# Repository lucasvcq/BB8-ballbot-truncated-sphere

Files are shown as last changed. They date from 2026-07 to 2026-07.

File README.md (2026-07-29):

# Ballbot — Self-Balancing Truncated-Sphere Robot

A truncated-sphere robot that moves by shifting its center of gravity and using a reaction wheel, controlled remotely through a web interface on a phone. Built from scratch over a full academic year by a team of 6.

## Overview

The robot's shape is a truncated sphere. Movement isn't achieved with wheels or legs, but by:

- **Shifting its internal center of gravity** to lean and roll in a direction
- A **reaction/inertia wheel** to control orientation and stabilize the robot

The whole system is piloted remotely via a **web interface accessible from a phone**.

Team of 6, full academic year (design, build, and control from scratch).

[📄 Poster](<RENDU FINAL/Blue Modern Scientific Poster (3).pdf>)

## My Role

- Embedded control code (Arduino + ESP32)
- Motor selection and driving
- Piloting/control logic (web interface ↔ robot communication)
- **Closed-loop control (asservissement)** for balance and movement
- Full wiring and soldering

## Tech Stack

- **Hardware:** Arduino, ESP32
- **Software:** HTML (web control interface), embedded C/C++
- **Modeling/Simulation:** MATLAB (control system modeling and simulation, used to design and validate the closed-loop control before implementation)
- **Tools:** VS Code, Git
- **Skills:** Soldering, closed-loop control design

## Architecture

```text
Phone (web interface, HTML)
        │  Wi-Fi
        ▼
     ESP32 ──► Arduino ──► Motors + Reaction wheel
        ▲
        └── Sensors (feedback for closed-loop control)
```

## Key Technical Points

- Designing a **closed-loop control system (asservissement)** to keep a spherical robot balanced and move it in a controlled direction using only a center-of-gravity shift + reaction wheel — no wheels/legs
- **Modeling and simulating the control system in MATLAB** before implementing it on hardware, to validate stability and tune parameters ahead of physical testing
- Wi-Fi communication between a phone-based web interface (ESP32) and the low-level motor control (Arduino)
- Mechanical design constraints of a truncated-sphere form factor

## Demo

<table border="0" style="border-collapse: collapse; border: none;">
  <tr style="border: none;">
    <td align="center" width="50%" style="border: none;">
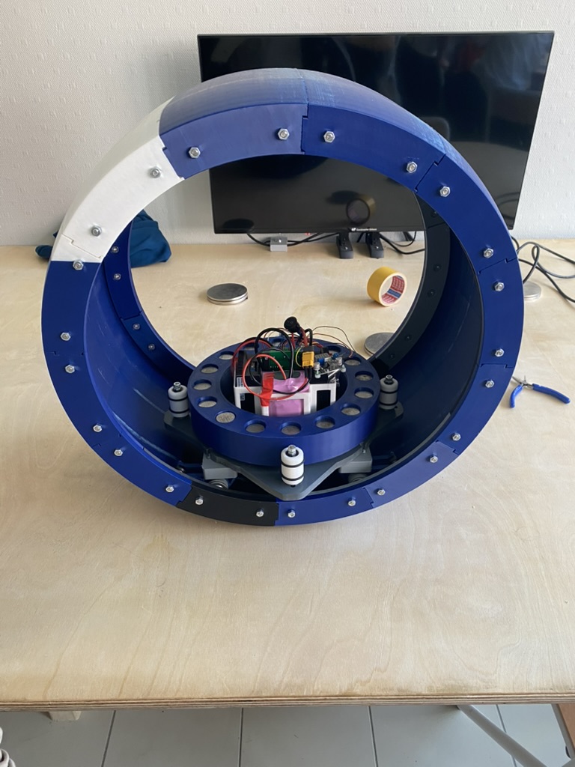
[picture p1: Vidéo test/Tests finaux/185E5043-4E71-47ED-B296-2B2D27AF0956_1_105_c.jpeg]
Picture of the robot
      
      <br>
      <sub>Picture of the robot</sub>
    </td>
    <td align="center" width="50%" style="border: none;">
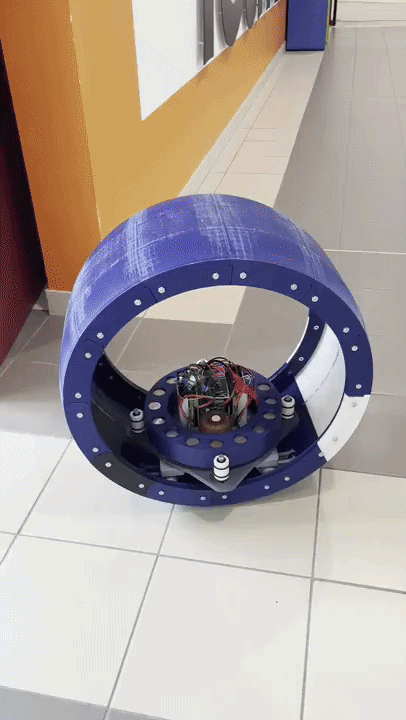
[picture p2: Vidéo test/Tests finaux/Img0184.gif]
Video of the robot moving
      
      <br>
      <sub>Video of the robot moving</sub>
    </td>
  </tr>
</table>

<!-- Add photos/video of the robot moving + the web control interface -->

## Context

School project — ICAM, 3rd year engineering, group project (6 students, full year, built from scratch).

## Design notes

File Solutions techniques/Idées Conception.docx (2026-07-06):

Idées Conception

- Le robot

On déplace notre masse sur les 3 axes dont un qui gère la direction et le reste sert pour le déplacement linéaire.

- Rail interne

contact par adhérence ou par engrenage

- 2 roues libres et 1 roue motorisée
- 1 roue libre et 2 roues motorisées
- Masse latérale

cette masse permet de faire pencher le robot pour le faire tourner, la commande dirigera l’angle que doit suivre le robot pour tourner correctement via les capteurs

- poulie courroie (contrôle X)
- pignon crémaillère
- vis sans fin
- (max speed)
- même système que la roue du rail interne mis en perpendiculaire (voir photo)
- Capteurs:
- Inclinomètre
- Gyroscope

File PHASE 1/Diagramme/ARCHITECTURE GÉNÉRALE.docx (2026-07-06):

Rail partiel

Masse latérale

Roue de contact motorisé

Capteur

Roues de contact libre

Batterie

Roue de contact motorisé

Carte de commande

Chassi

Rail

Masse principale

Roues de contact libre

Composants électroniques

Support masse latérale

Roue principale

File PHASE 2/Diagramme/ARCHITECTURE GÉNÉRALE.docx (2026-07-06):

Roue de contact motorisé

Roue de contact motorisé

Roues de contact libre

Composants électroniques

Roue d’inertie

Capteur

Roues de contact libre

Batterie

Carte de commande

Chassi

Roue principale

Rail

Masse principale

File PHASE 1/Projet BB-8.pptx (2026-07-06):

## Projet BB-8

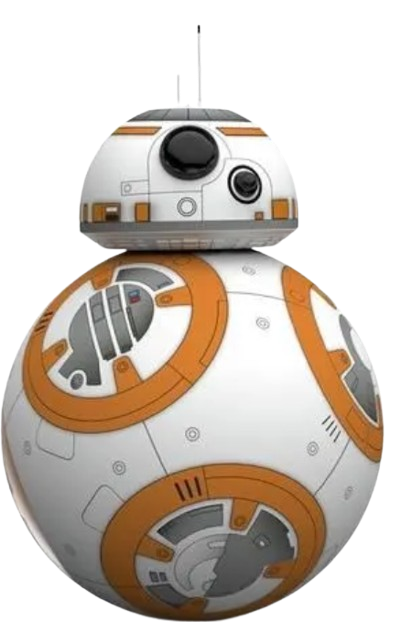
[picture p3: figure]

Groupe : I_Roue_6

## Sommaire

- Organigramme de l'équipe
- Veille sur l'existant
- Diagramme pieuvre et FAST
- Audit sur l’existant
- Planning
- Conclusion

## Organigramme de l’équipe

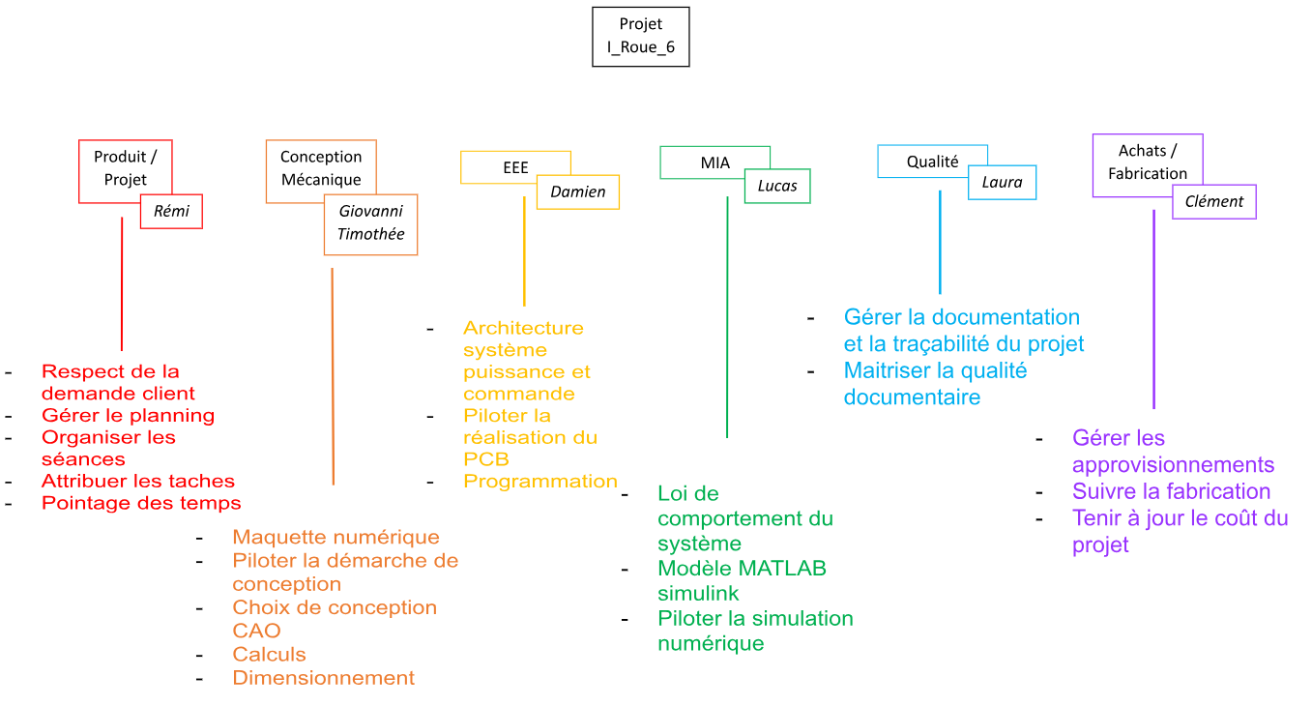
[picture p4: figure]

## Veille sur l’existant

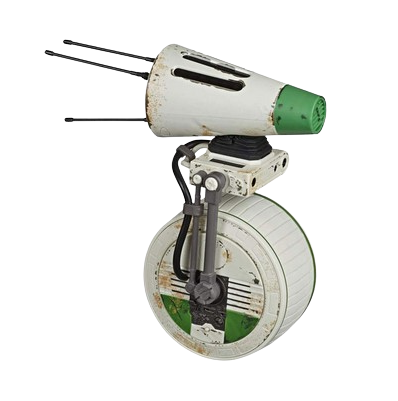
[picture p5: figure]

Robot Gyroroue
- Système mono roue avec capacité de tourner par inclinaison du centre de masse
- Centre de masse à l'extérieur

Robot D-0 inspiration star wars
- Deux roues disjointes
- Système intéressant mais pas
compatible avec le cahier des charges

Ringbot
- Centre de masse dans la roue
- Roue creuse
- Roule grâce au déplacement du centre de masse sur les rails intérieurs
- Equilibrage grâce au déplacement du centre de masse le long de l’axe de la roue
- Système le plus intéressant pour nous

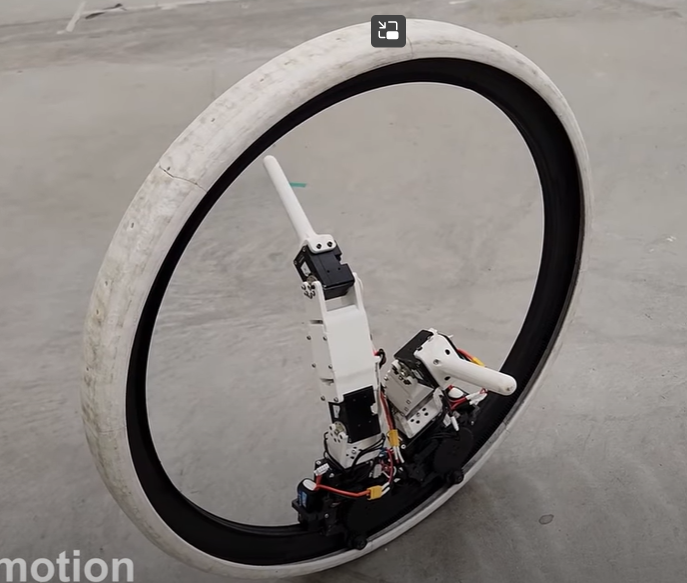
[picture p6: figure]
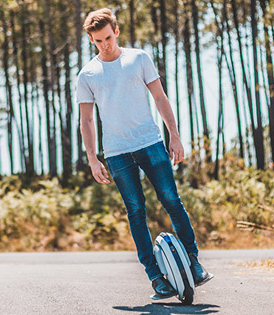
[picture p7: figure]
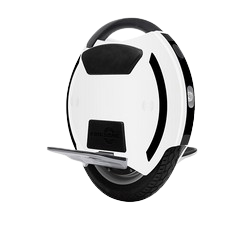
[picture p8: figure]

## Diagramme pieuvre et FAST

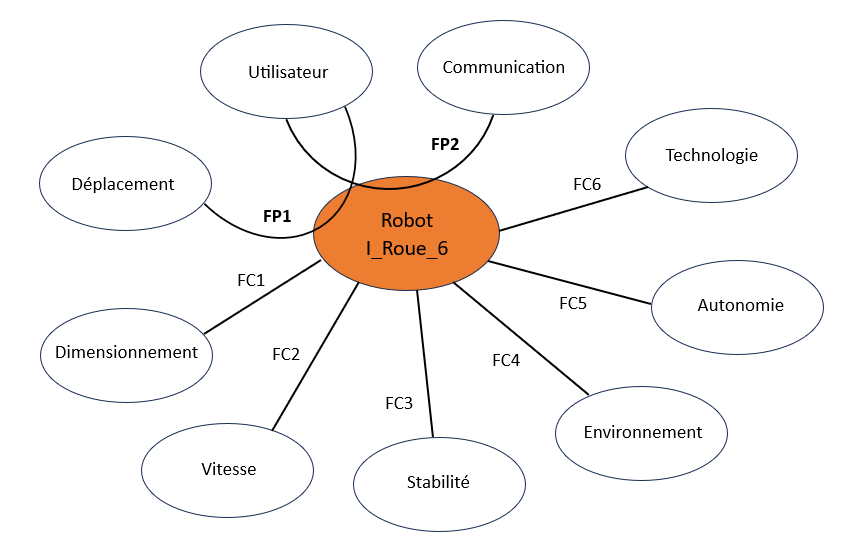
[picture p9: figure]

Diagramme FAST

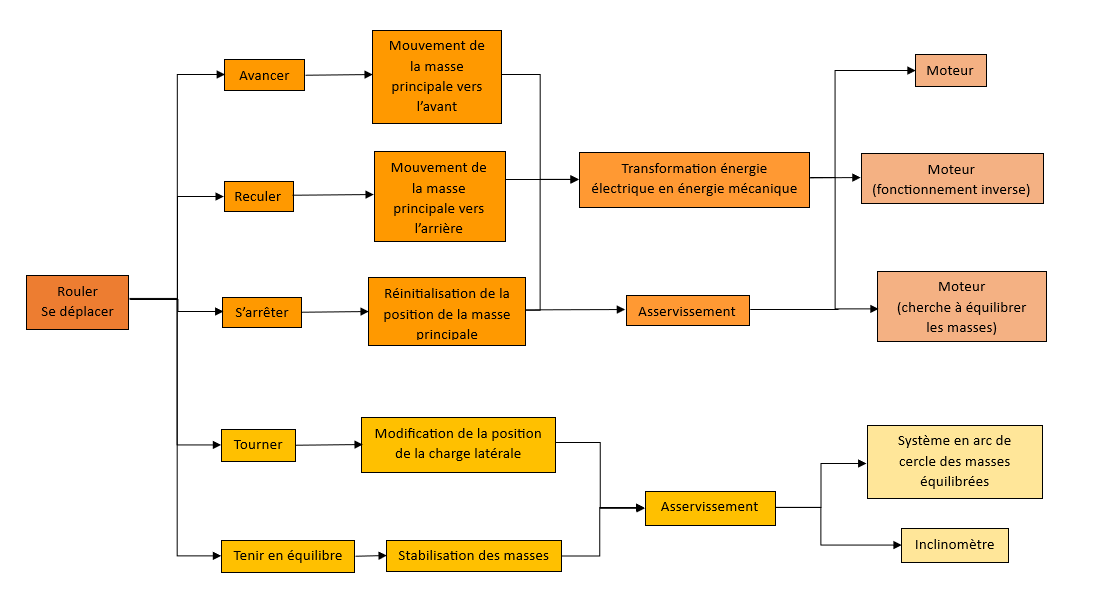
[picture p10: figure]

Diagramme pieuvre

## Audit sur l’existant

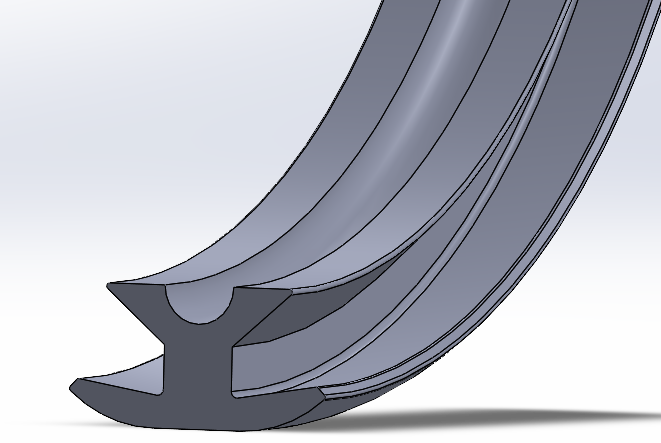
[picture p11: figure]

Rail interne
- Quatre roues libres et
une roue motorisée
=> On déplace la masse principale
=> Déplacement linéaire de la
masse pour le faire

Masse latérale
- Permet de faire
pencher le robot
pour le faire tourner

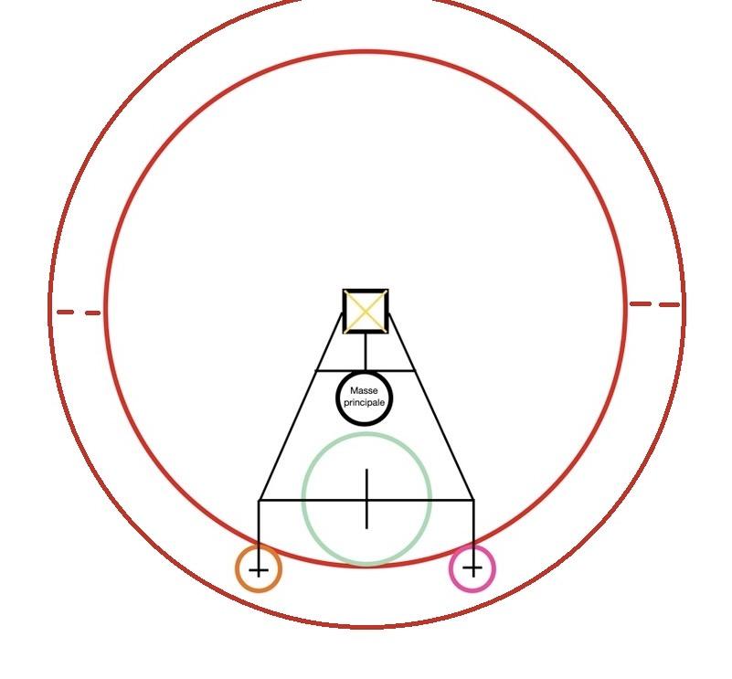
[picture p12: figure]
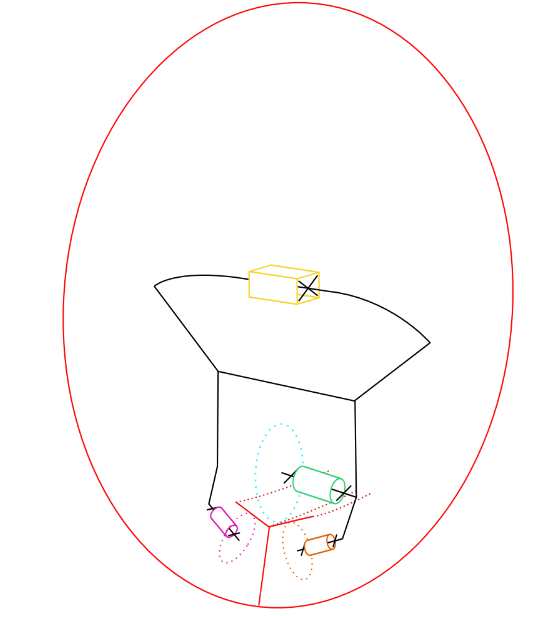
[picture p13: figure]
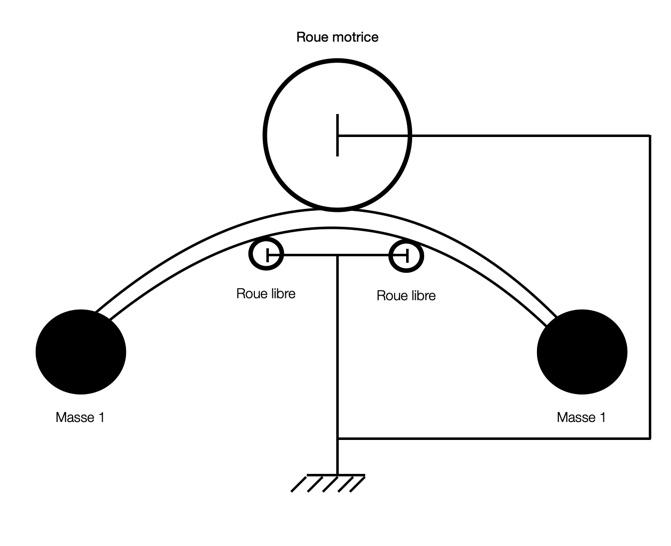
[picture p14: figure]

z

Schéma 3D

x

y

## Planning

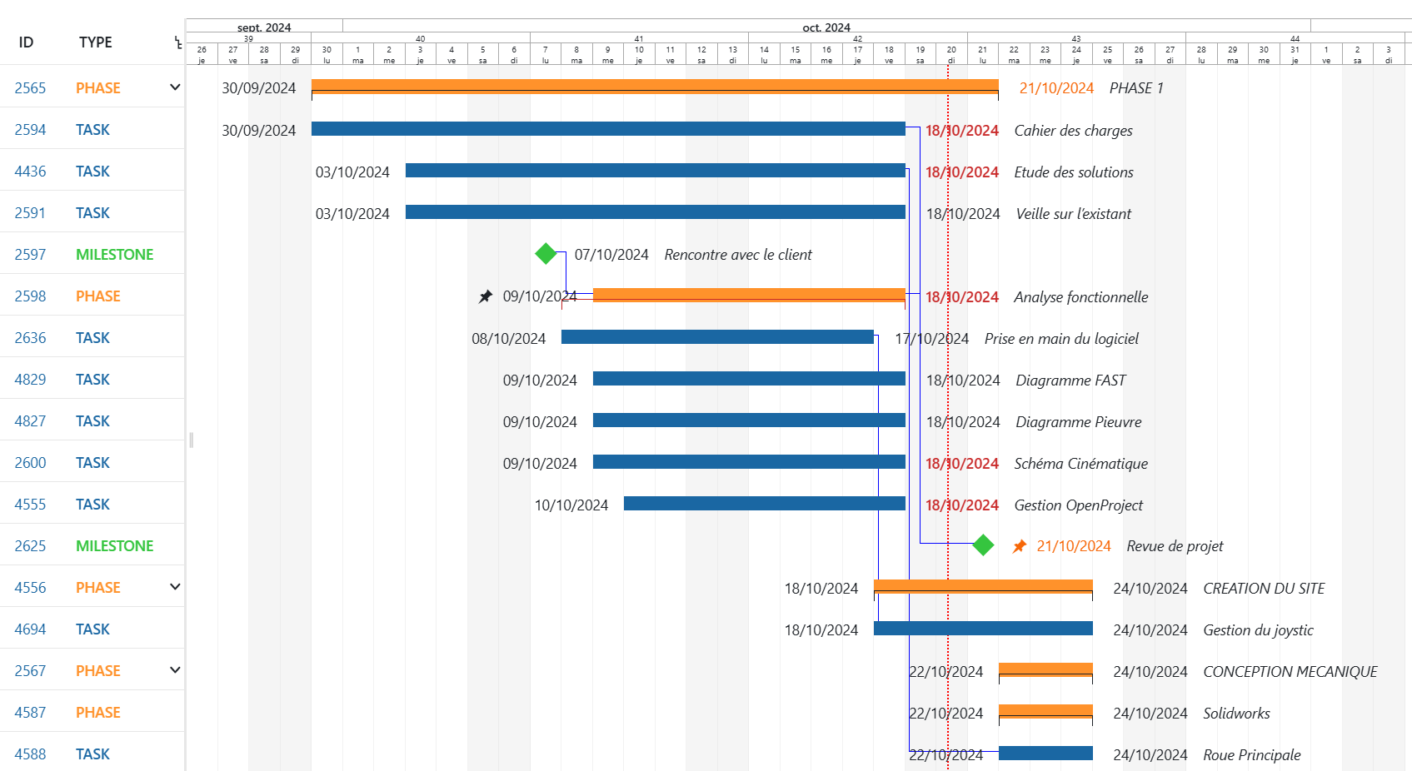
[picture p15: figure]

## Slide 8

Conclusion

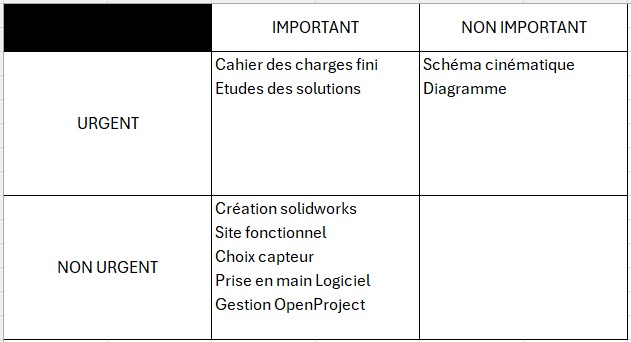
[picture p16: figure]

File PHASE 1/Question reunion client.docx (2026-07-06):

Question réunion client

Conception

- Quelles sont les dimensions et poids max du robot ?

Fabrication / proto en 3D / 200x200x200 ? / liberté de choix / 50/60 cm de hauteur minimum et 20/30 cm de large

- Quelle doit être la résistance du robot (matériaux) ?

impression 3D /

- Quel doit être le type de déplacement du robot (sur 2 roues type D-0,... ) ?

Peut tout faire / ne pas faire en 2 roues / déplacement de centre de gravité

- Adhérence robot (quelle type de sol/ passage d’obstacle)

sol lisse

- Y’a-t-il des obstacles ? Y’a-t-il besoin d’amortisseurs ?

Surface plane / intérieur

- Quelle limite de vitesse?

Il en faut une / 10 km/h à Vmax et 3-4 km/h en moyenne

- Autonomie ? Branché, batterie ?

batterie de 2h

- Doit-on prévoir un module de liaison avec un autre groupe (par exemple le plateau sur le dessus/ attache sur les côtés) ?

Non pour l’instant / Ajouter une tête si on a le temps

- Comment le pilote-t-on, à quelle distance (manette, téléphone…) ?

Application téléphone avec QR code

Achat / Fabrication

- Quelles sont les attentes budgétaires ?

500 eu / première année => peut être plus de budget

- Y’a-t-il des matériaux à utiliser obligatoirement? (peut-on utiliser les matériaux que l’on souhaite?)

3D PLA / arbres usinés au tour

- Y’a-t-il des méthodes de fabrication à ne pas utiliser ?

/

- Doit-il pouvoir résister aux éléments extérieurs? (résistance aux éclaboussures…?)

Intérieur pour l’instant

Programmation

- A-t-on une carte et/ou un langage imposé ?

C / C++ sur ESP32

Qualité

- Diagramme Pieuvre et Fast ?

Pieuvre milieu extérieur a partir de quoi on prévoit les fonctions

Fast architecture de notre système

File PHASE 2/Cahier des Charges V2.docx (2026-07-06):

PHASE2

CAHIER DES CHARGES

Groupe projet : 6

Robot roue type BB-8

SUIVI DES VERSIONS

Indice | Date | Modification | Approbation | Vérification | Rédaction
| | Modification n°1
A | 07/10/2024 | Création | | Laura | Laura/Rémi
B | 22/10/2024 | Modification 1 | | Laura | Laura/Rémi
| | | Nom Approb. | Nom Resp. | Nom Ingé.

LISTE DE DIFFUSION

Clients / Équipe | Nom
Produit/Projet | MAHOT Rémi
Conception | DAME Giovanni
Mécanique | DECAUDIN Timothée
EEE | DEGUILHEM Damien
MIA | VACQUIE Lucas
Qualité | SEBASTIEN Laura
Achat/Fabrication | BARIC Clément

sommaire

1 GÉNÉRALITÉS 6

1.1 OBJECTIF 6

1.2 DONNÉES D’ENTRÉE 6

2 VEILLE SUR L’EXISTANT 7

2.1 PRODUITS EXISTANTS (avec liens internet) 7

2.2 TENDANCES – ÉVOLUTIONS 9

2.3 Synthèse DE VOTRE VEILLE 9

3 ENVIRONNEMENT DU PRODUIT 10

3.1 CONDITIONS D’UTILISATIONS 10

4 PISTES D’INNOVATIONS 11

4.1 VOS IDÉES EN VRAC ET EN NOMBRE 11

4.2 LES IDÉES RETENUES PAR L'ÉQUIPE PROJET 12

5 ANALYSE FONCTIONNELLE EXTERNE 13

5.1 APPROPRIATION DU BESOIN – REFORMULATION 13

5.2 EXPRESSION FONCTIONNELLE DU BESOIN 13

5.2.1 DIAGRAMME PIEUVRE 13

5.2.2 LISTE DES SPÉCIFICATIONS FONCTIONNELLES 14

6 ANALYSE FONCTIONNELLE INTERNE 16

6.1 DIAGRAMME FAST 16

6.2 ARCHITECTURE GÉNÉRALE DU système - SOUS-ENSEMBLES FONCTIONNELS 16

7 DOCUMENTATION SPÉCIFIQUE AU PROJET 17

7.1 Normes 17

7.2 AUTRES DOCUMENTS 17

glossaire

- Accéléromètre

Appareil mesurant l’accélération et la vitesse d'inclinaison d'un objet par rapport à un référentiel donné (souvent par rapport à la ligne d'horizon).

- Gyroscope

Un appareil constitué d'un disque dont l'axe de rotation est libre de prendre toutes les orientations possibles, mis en rotation autour d'un de ses axes principaux, celui-ci conserve son axe de rotation invariable. Ainsi, les gyroscopes sont utilisés comme capteur de position angulaire selon un ou deux axes uniquement.

- Roue inertielle

Dispositif mécanique constitué par une masse équilibrée maintenue en rotation continue autour d'un axe, utilisé soit pour stabiliser un système par effet gyroscopique soit pour accumuler de l'énergie.

1 GÉNÉRALITÉS
  1.1 OBJECTIF

L’objectif principal de notre projet est de développer un premier prototype fonctionnel de robot roue motorisée et pilotable à distance.

  1.2 DONNÉES D’ENTRÉE

Comme il s’agit d’un nouveau projet, nous possédons une certaine liberté dans nos choix de conception. Cependant, afin de répondre aux attentes du client, nous avons toutefois quelques contraintes à respecter.

Concernant la forme et les dimensions du robot, il s’agira d’une roue tronquée de 60 cm de diamètre et 30 cm d’épaisseur. Avec un diamètre de roue suffisamment grand, on peut obtenir rapidement la vitesse souhaitée et l’épaisseur de la roue nous permet d’obtenir l’équilibre nécessaire pour stabiliser le robot sans pour autant que cela nous impacte lors de ses rotations.

En effet, le robot doit pouvoir se déplacer dans l’espace en roulant. Pour cela, il doit savoir s’arrêter, avancer et reculer en ayant une vitesse moyenne de 3-4 km/h et un seuil maximal de 7 km/h. Il doit savoir aussi tourner dans toutes les directions ainsi que sur lui-même.

Pour le faire avancer, on va chercher à mettre en mouvement son centre de gravité en le faisant se déplacer le long du rail de la roue. Quant à l’action de tourner, on va utiliser une roue d’inertie qu’on mettre en rotation afin que le robot puisse tourner même à l’arrêt sur lui-même.

Concernant la partie programmation du robot, il nous est imposé de coder en C ou C++ puisque nous devons utiliser des cartes ESP32. On utilisera notamment des moteurs précis et rapides afin que les déplacements de notre robot soient les plus fluides possibles. Pour que notre robot soit autonome, il faut qu’il dispose d’une batterie interne qu’on puisse recharger lui permettant de tenir deux heures en fonctionnement entre chaque rechargement.

Pour son utilisation, il doit être pilotable à partir d’une application de téléphone. Pour un accès au grand public, il suffira à l’utilisateur de scanner un QR code pour accéder au pilotage du robot.

2 VEILLE SUR L’EXISTANT
  2.1 PRODUITS EXISTANTS (avec liens internet)
- Robot D-0 inspiration star wars

https://youtu.be/zplirkxl6iM?si=WKp0uwwly6SlCgs7

Ce robot est une reproduction d’un robot de la saga star wars. Il a été réalisé en imprimante 3D. Son fonctionnement est basé sur deux roues qui s’apparentent en une seule et fonctionnent indépendamment. Ainsi, pour que le robot avance ou recule, il faut que les deux roues fonctionnent de manière synchronisée et aillent dans la même direction. Pour faire tourner une rotation, l’une des deux roues va avancer pendant que l’autre va reculer. Cette conception avantageuse permet donc au robot de pouvoir tourner sur lui-même.

Cette idée nous semblait être la meilleure pour réaliser le robot mais suite à notre entrevue avec le client, il nous a été imposé de réaliser un robot composé que d’une seule et même roue. Nous avons donc dû abandonner cette idée.

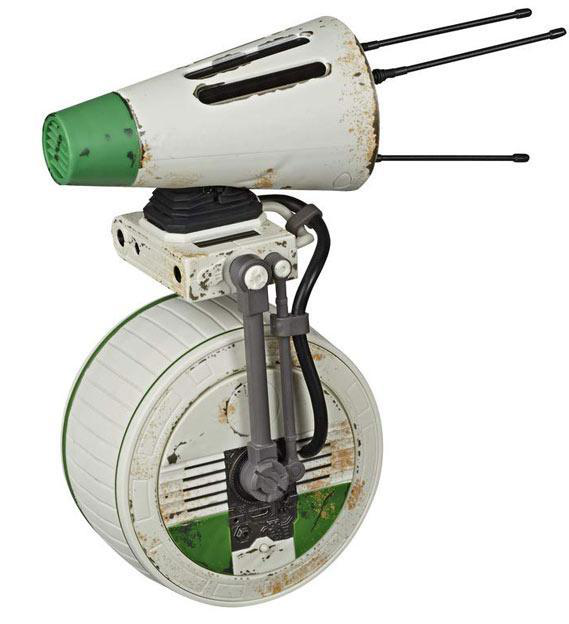
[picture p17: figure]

- Robot Gyroroue

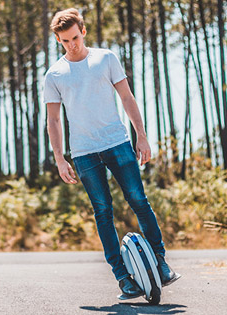
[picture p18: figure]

La Gyroroue est composée d’un bâti qui est lié à une roue contrôlée par un moteur. Le bâti est donc à l'extérieur de la roue et ce sont les mouvements de l’utilisateur qui lui permettent de tourner (centre de gravité).

L’idée de la rotation par centre de gravité ne répond que partiellement à notre problématique pour tourner.

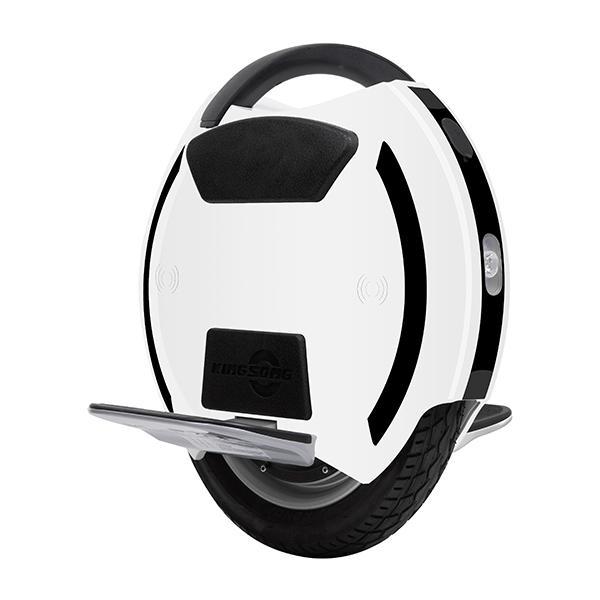
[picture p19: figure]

- Ringbot

https://www.youtube.com/watch?v=DX3DMEreDyk

La particularité de ce robot est l’utilisation d’un système de stabilisation avancé pour maintenir l’équilibre sur une seule roue, similaire au fonctionnement d'un gyroscope.

Le Ringbot peut se déplacer en avant, en arrière, et même tourner sur lui-même en modifiant la vitesse de rotation de sa roue. Sa conception le rend agile et capable de se déplacer sur différents terrains tout en maintenant un équilibre stable.

Nous avons choisi de partir sur cette conception de roue avec un déplacement axial. Cependant, nous ne comptons pas recréer les bras dont il dispose pour se redresser.


  2.2 TENDANCES – ÉVOLUTIONS

Dans un premier temps, notre objectif principal est de réaliser un robot fonctionnel respectant le cahier des charges. Cependant, pour améliorer notre robot afin de le rendre plus autonome et performant, nous pouvons envisager plusieurs perspectives d’évolution qui sont les suivantes:

- Déplacement en milieu contraint (pluie, obstacle, sol granuleux)
- Augmentation de la vitesse
- Ajout d’un détecteur d’obstacle d’abord à l’avant et à l’arrière du robot puis sur 360°
- Ajout d’une tête au robot
- Ajout d’une caméra sur la tête du robot qui retransmet l’image sur le téléphone de l’utilisateur
- Travail sur l’esthétisme
  2.3 Synthèse DE VOTRE VEILLE

Après avoir exploré plusieurs concepts de robots, trois modèles ont retenu notre attention : le robot D-0 de Star Wars, la Gyroroue, et le Ringbot.

Le D-0, fonctionnant par deux roues indépendantes, a été écarté en raison de la contrainte imposée par le client d'avoir une roue en une seule partie.

La Gyroroue, avec son mécanisme de contrôle par le centre de gravité, aurait pu inspirer la méthode de rotation du robot. Cependant, cette solution ne permet pas de répondre complètement aux besoins du client puisque le robot doit pouvoir tourner sur lui-même à l’arrêt.

Finalement, le design du Ringbot, qui utilise une roue unique pour se déplacer tout en maintenant son équilibre, a été retenu.

Suite à une mise au point avec le client, notre choix final de conception s'oriente vers un robot de type Ringbot, mais sans inclure les bras de stabilisation. Ainsi, nous devons apporter une solution différente pour faire tourner le robot.

3 ENVIRONNEMENT DU PRODUIT
  3.1 CONDITIONS D’UTILISATIONS

L’utilisation de notre robot se fera dans une salle fermée. Ainsi, nous n’avons pas de contraintes météorologiques à prendre en compte comme par exemple le vent ou les intempéries.

De plus, le robot roulera sur un sol adhérent qui sera une surface plane et lisse. Il n’aura aucun obstacle à éviter de lui-même.

Comme nous serons dans une salle fermée, ce sera à l’utilisateur de prendre en compte la distance qui sépare le robot des murs et de les éviter pour ne pas endommager le robot.

4 PISTES D’INNOVATIONS
  4.1 VOS IDÉES EN VRAC ET EN NOMBRE
    4.1.1 PISTES NON-VIABLES

Initialement, nous avions compris que le robot devait pouvoir tourner que lorsqu’il était en mouvement et non aussi à l’arrêt. Ainsi, nous avons élaboré la solution suivante à partir des différents éléments évoqués en dessous.

On déplace notre masse sur les 3 axes dont un qui gère la direction et le reste sert pour le déplacement linéaire.

Rail interne

Contact par adhérence ou par engrenage

- Deux roues libres et une roue motorisée
- Une roue libre et deux roues motorisées

Masse latérale

Cette masse permet de faire pencher le robot pour le faire tourner. La commande dirige l’angle que doit suivre le robot pour tourner correctement via les capteurs.

- Poulie courroie (Contrôle X)
- Pignon crémaillère

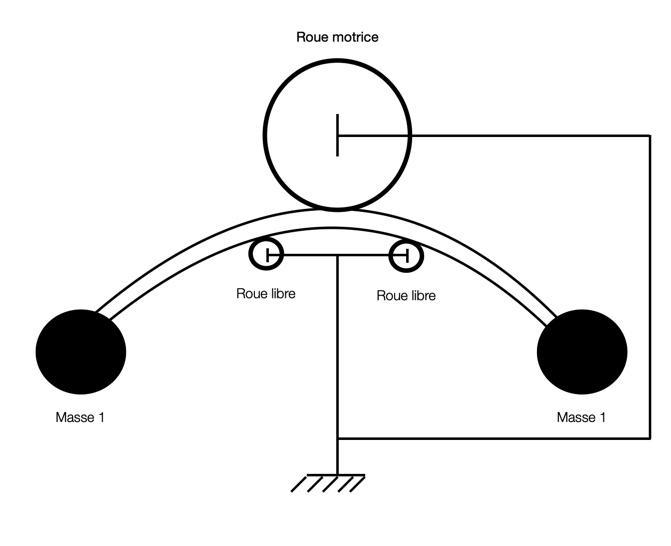
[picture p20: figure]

- Vis sans fin
- Système du Max speed
- Même système que la roue du rail interne mis en perpendiculaire

Capteurs

- Inclinomètre
- Gyroscope
    4.1.2 PISTES VIABLES

Après une entrevue avec le client, nous avons dû repenser à nos solutions car elles ne prenaient pas en compte toutes les contraintes imposées, notamment le fait que le robot doit pouvoir tourner sur lui-même en étant à l’arrêt.

Nous avons alors pensé à une roue inertielle. En effet, cette solution nous permet de tourner à l’arrêt comme en mouvement. Par conséquent, avec cette nouvelle solution en application, nous avons dû modifier notre système afin que cette roue inertielle puisse être montée sur notre système.

Nous avons repris l’idée du rail mais en changeant sa configuration. Ainsi, nous sommes partis de la structure simple de la roue tronquée et nous avons remonté les bords pour bloquer le châssis en translation.
Dans ce nouveau “rail”, on a donc une plateforme montée sur 4 roues libres et une roue motorisée qui se déplace afin de faire avancer le robot linéairement. C’est notamment sur cette plateforme motorisée qu’on disposera nos composants comme la batterie. De plus, on montera une seconde roue motorisée dont son axe sera perpendiculaire à la plateforme et qui servira à faire tourner la roue inertielle.

  4.2 LES IDÉES RETENUES PAR L'ÉQUIPE PROJET

Déplacement du robot

Le déplacement du robot se fait en modifiant la position du centre de masse dans l’axe du rail. Cette solution permettra de faire avancer le robot linéairement.

Afin de le faire tourner, on utilise une roue d’inertie. Cette solution permet au robot de pouvoir tourner tout en roulant mais aussi en étant à l'arrêt.

Équilibre

Notre robot doit être asservi pour pouvoir constamment garder l’équilibre, il doit ainsi déplacer son centre de masse à tout moment pour pouvoir pallier un déséquilibre inattendu.

Communication

L’utilisateur doit scanner un QR code positionné sur le robot pour pouvoir l’utiliser. Ce QR code connectera l’utilisateur au robot en le connectant au réseau wifi généré par la carte ESP 32. Pour assurer le bon fonctionnement du robot, la portée du signal doit couvrir une distance de 10m à 15m. A partir de l’application qui sera disponible sur IOS et Androïd, l’utilisateur pourra contrôler le robot grâce à un joystick permettant de gérer les déplacements, rotations et accélérations du robot.

5 ANALYSE FONCTIONNELLE EXTERNE
  5.1 APPROPRIATION DU BESOIN – REFORMULATION

Le but de ce projet est de concevoir et de créer un robot pouvant se déplacer dans toutes les directions en roulant, y compris pouvoir tourner sur lui-même même à l’arrêt.

Pour son utilisation, le robot devra être pilotable par un utilisateur à travers une application de téléphone qui sera rendue accessible au grand public.

  5.2 EXPRESSION FONCTIONNELLE DU BESOIN
    5.2.1 DIAGRAMME PIEUVRE

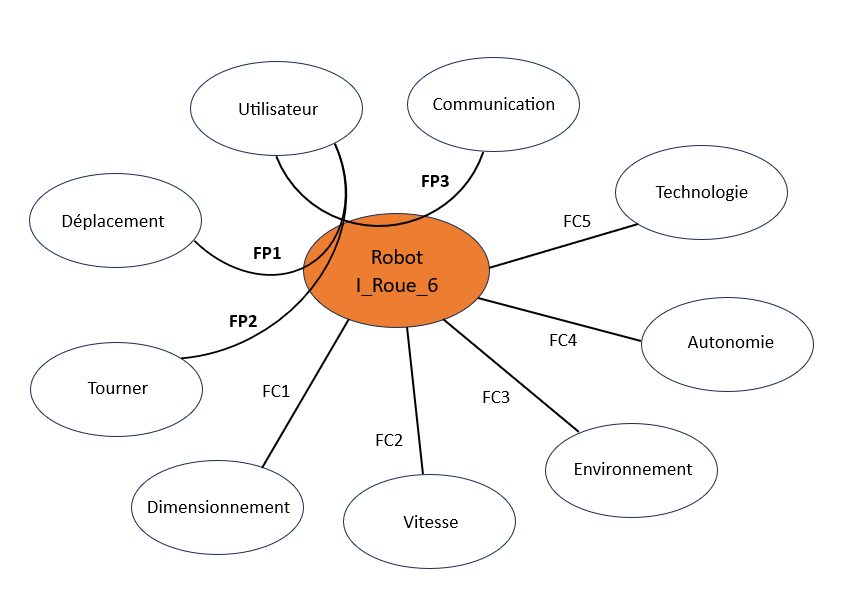
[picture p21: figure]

    5.2.2 LISTE DES SPÉCIFICATIONS FONCTIONNELLES

Fonction | Critères de performance | Niveau de priorité (NP) | Niveau de conformité (NC) | Niveau de risque (NR) | Observations
FP1 Déplacement dans l’espace | Le robot doit pouvoir se déplacer dans l’espace en tournant | 2 | 2 | 2 | Robot motorisé
FP2 Tourner sur lui-même | Le robot doit pouvoir tourner sur lui-même même à l’arrêt | 2 | 2 | 2 | Roue d’inertie motorisée
FP3 Robot pilotable à distance | Le robot doit pouvoir être accessible et pilotable par le grand public | 2 | 2 | 2 | Application mobile sur IOS et Androïd
FC1 Dimensionnement | Le robot doit respecter les dimensions fixées Diamètre: 60 cm Epaisseur: 30 cm | 1 | 1 | 1
FC2 Vitesse | Le robot doit atteindre une vitesse moyenne de 3-4 km/h et une vitesse maximale de 7 km/h | 1 | 1 | 2 | Moteurs rapides avec un couple important
FC3 Environnement | Le robot doit rouler sur une surface adhérente, plane et lisse | 2 | 1 | 1 | Pas de conditions météorologique à prendre en compte
FC4 Autonomie | Le robot doit pouvoir tenir 2h en fonctionnement | 1 | 2 | 1 | Batterie rechargeable
FC5 Technologie | Le robot doit fonctionner et être programmé en C ou C++ | 1 | 2 | 1 | Utilisation de carte ESP32

NP (Niveau de priorité)

- 0 : Faible
- 1 : Moyen
- 2 : Maximum

NC (Niveau de conformité)

- 0 : Non conforme
- 1 : Partiellement conforme
- 2 : Conforme

NR (Niveau de risque)

- 0 : Nul
- 1 : Moyen
- 2 : Majeur
6 ANALYSE FONCTIONNELLE INTERNE
  6.1 DIAGRAMME FAST

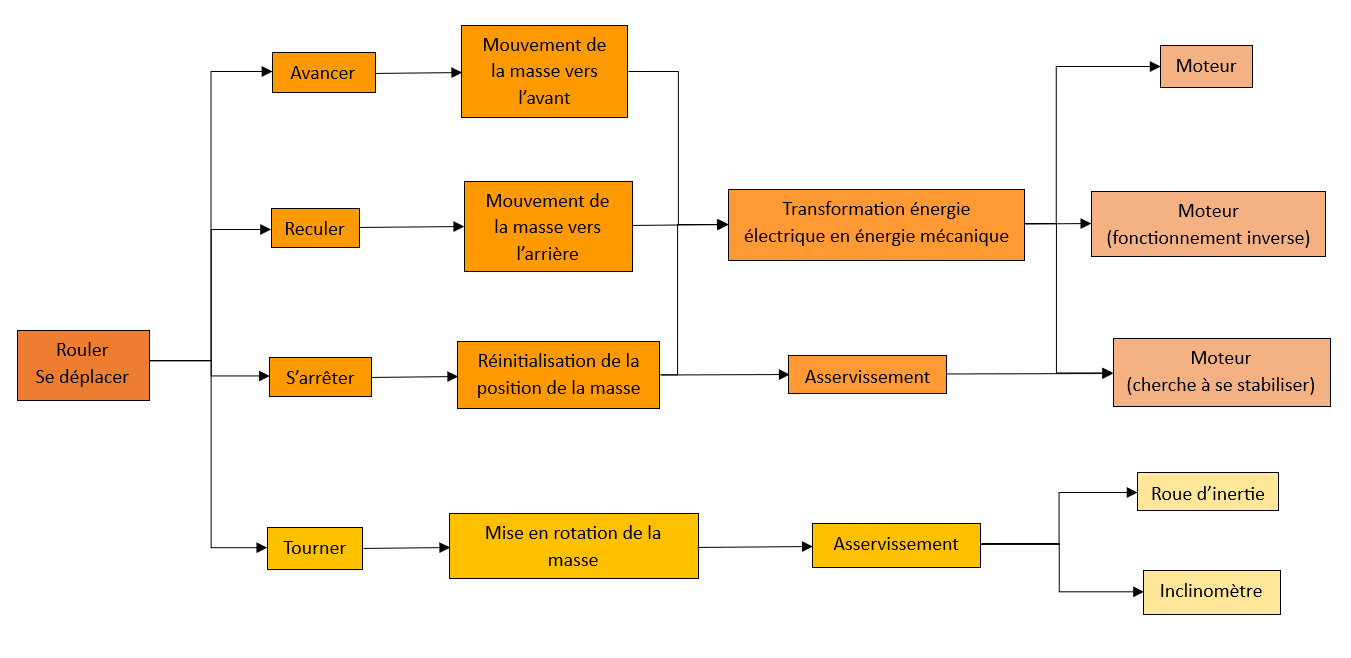
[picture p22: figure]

  6.2 ARCHITECTURE GÉNÉRALE DU système - SOUS-ENSEMBLES FONCTIONNELS

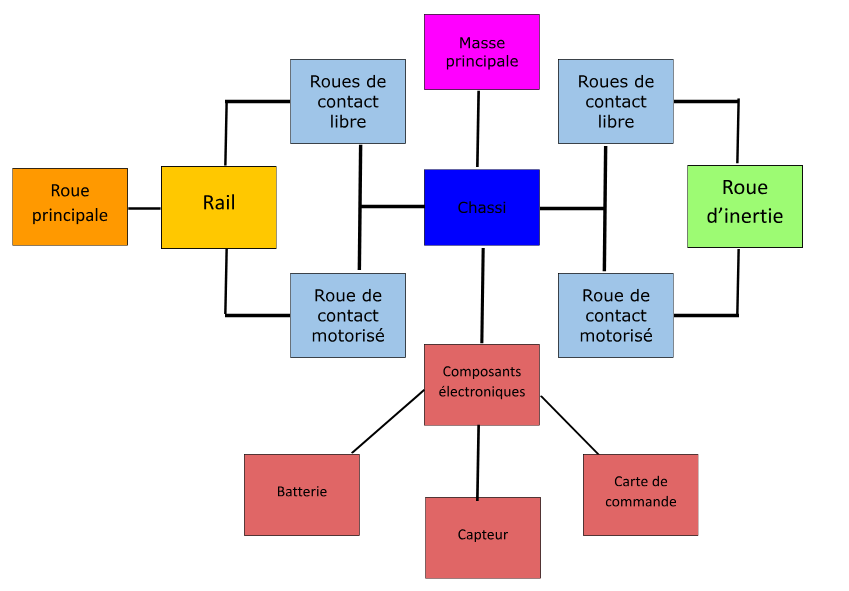
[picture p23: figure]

7 DOCUMENTATION SPÉCIFIQUE AU PROJET
  7.1 Normes
  7.2 AUTRES DOCUMENTS

Institut Catholiqued’Arts et Métiers 75, avenue de Grande-Bretagne, 31300 Toulouse http://icam.groupe-icam.fr

ICAM –F001 Page / Toute communication ou reproduction, même partielle, est strictement interdite sans autorisation écrite de l’ICAM

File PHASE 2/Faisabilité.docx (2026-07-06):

PHASE FAISABILITÉ

Groupe projet : 6

Robot roue type BB-8

LISTE DE DIFFUSION

Clients / Équipe | Nom
Produit/Projet | MAHOT Rémi
Conception | DAME Giovanni
Mécanique | DECAUDIN Timothée
EEE | DEGUILHEM Damien
MIA | VACQUIE Lucas
Qualité | SEBASTIEN Laura
Achat/Fabrication | BARIC Clément

sommaire

1 VUES CA0 DE VOTRE PROJET 4

1.1 SCHÉMAS DE PRINCIPE (CINÉMATIQUE SI BESOIN) 4

1.2 VUES CAO (EnSEMBLE ET DÉTAILS DES SOLS OU MODIFS APPORTÉES) 4

2 SPÉCIFICATIONS EN MÉCANIQUE 5

2.1 HyPOTHÈSES RETENUES POUR VOS CALCULS 5

2.2 VOS CALCULS DE PRÉDIMENSIONNEMENT 5

3 SPÉCIFICATIONS EN EEE 7

3.1 SCHÉMA DE PUISSANCE ET DE COMMANDE 7

3.2 ALGORITHME (DECOMPOSITION LOGICIELLE) 7

4 SPÉCIFICATIONS EN MIA 8

4.1 VOS BESOINS D’ASSERVISSEMENTS 8

4.2 AVANCEMENT SUR MATLAB SIMULINK 8

5 CHOIX DES COMPOSANTS 9

5.1 VOTRE PRÉ-SÉLECTION DE COMPOSANT (méca) 9

5.2 VOTRE PRÉ-SÉLECTION DE COMPOSANT (EEE) 10

6 GESTION DE PROJET 11

6.1 EVALUATION DES RISQUES DU PROJET 11

6.2 AVANCEMENT DU PROJET (COURBE EN S) 12

# 1 VUES CA0 DE VOTRE PROJET

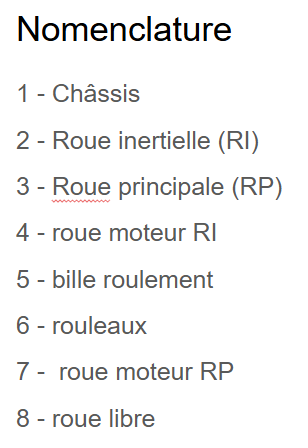
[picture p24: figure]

## 1.1 SCHÉMAS DE PRINCIPE (CINÉMATIQUE SI BESOIN)

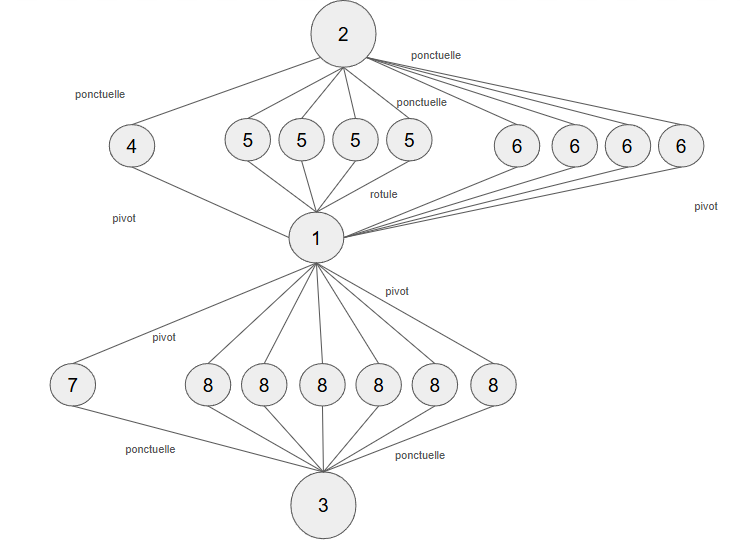
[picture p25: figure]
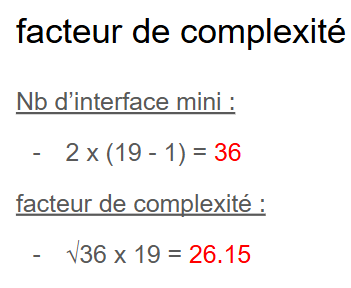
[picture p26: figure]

## 1.2 VUES CAO (ENSEMBLE ET DÉTAILS DES SOLS OU MODIFS APPORTÉES)


# 2 SPÉCIFICATIONS EN MÉCANIQUE

## 2.1 HYPOTHÈSES RETENUES POUR VOS CALCULS

Le robot est de forme cylindrique, il avance grâce à une masse mobile qui se déplace dans son intérieur. De plus, il doit pouvoir tourner sur lui-même à l'arrêt et effectuer des mouvements rotatifs en roulant. Pour cela, on utilise une roue giratoire. Pour le dimensionnement, on prend uniquement les frottements du robot sur le sol en carrelage en compte, ce qui nous donne le coefficient de frottement.

Données: R => Roue principale du Robot

r => roue giratoire

mR = 5kg largeur roue principale L = 300mm

rayon intérieur r1 = 115mm rayon extérieur r2 = 150mm

rayon extérieur R1 = 300mm rayon intérieur R2 = 290mm

g = 9.81m/s² ωR = ⅖ π rad/s

μ = 0.35 coefficient de frottement ωr = 50/3 π rad/s t = 5s

## 2.2 VOS CALCULS DE PRÉDIMENSIONNEMENT

Dimensionnement masse roue giratoire

| Mr = 1.8116 kg Dimensionnement couple moteur roue giratoire
| C= 0.85 Nm
| Dimensionnement moteur roue principale Cm le couple nécessaire pour déplacer le robot: Cm = 0.41 Nm ωm la vitesse angulaire nécessaire au déplacement du robot à 10 km/h ωm = 55.56 rad/s

# 3 SPÉCIFICATIONS EN EEE

## 3.1 SCHÉMA DE PUISSANCE ET DE COMMANDE


## 3.2 ALGORITHME (DECOMPOSITION LOGICIELLE)


Afin de mettre en mouvement notre robot, nous avons besoin de 2 moteurs MCC, un pour avancer et l’autre pour tourner. Chaque moteur est connecté par 8 fils au driver : 3 d’entre eux permettent d’assurer la transmission de la commande, 3 autres sont reliés à l’encodeur du moteur afin de récupérer les données et enfin les 2 derniers sont pour l’alimentation.

Nous avons donc besoin de 2 drivers, soit un par moteur. Les drivers servent à piloter les moteurs et à récupérer les données. On peut décomposer ses fonctions en 2 chemins d’accès:

- Carte -> Driver -> Moteur -> Piloter moteur
- Encodeur -> Driver -> Carte -> Récupérer données

Pour répondre à nos besoins d’asservissement, on possède un accéléromètre qui va nous permettre de relever l’accélération et la vitesse angulaire à chaque position du robot pour ensuite pouvoir transmettre l’information aux moteurs qui vont ajuster les déplacements du robot afin qu’il reste stable. Il est aussi important que la position du robot soit cohérente avec celle définie par le joystick et dont sa position est transmise en wifi au robot.

Actuellement, on a réalisé des tests pour comprendre le fonctionnement du driver.
On possède déjà des programmes pour les 2 moteurs MCC mais comme on ne va pas utiliser les mêmes drivers, on va devoir apporter des modifications dans le code afin de l’adapter aux drivers.

Concernant le site web, on a créé un réseau wifi avec la carte. On a réussi à connecter un téléphone en wifi à la carte. Ainsi, on arrive à accéder et lancer le site internet depuis le téléphone afin de manipuler le joystick et de récupérer ses données sur la carte.

La prochaine étape est de coder l’accéléromètre. De plus, quand on aura nos moteurs, on pourra commencer à adapter nos programmes pour les moteurs afin qu’il marche pour nos drivers. Pour le site web, on veut améliorer le visuel du site web pour le rendre plus esthétique.

# 4 SPÉCIFICATIONS EN MIA

## 4.1 VOS BESOINS D’ASSERVISSEMENTS

On va avoir besoin d’asservir le moteur qui nous permet de faire avancer le robot afin de s’assurer de garder la position définie pour aller à la vitesse voulue. L’asservissement va aussi nous permettre d’arrêter le plus rapidement possible le robot.

L’accéléromètre, positionné sur le châssis, nous permet de récupérer une vitesse donnée correspondant à la bonne position du joystick.

## 4.2 AVANCEMENT SUR MATLAB SIMULINK

De nombreuses difficultés ont été rencontrées lors de la manipulation de Matlab et Simulink. Ainsi, nous avons décidé de concentrer nos efforts sur la conception du SOLIDWORKS, ce qui nous a laissé peu de temps pour la prise en main de Matlab.

# 5 CHOIX DES COMPOSANTS

## 5.1 VOTRE PRÉ-SÉLECTION DE COMPOSANT (méca)

Désignation | Fournisseur | Réf fournisseur | qté | Montant TTC | Lien internet
Roulement 1 bille | Amazon | | Vendu par 12 | 17,99 | https://www.amazon.fr/CODIRATO-Roulettes-Transfert-Universels-Transmission/dp/B09XDNCL2L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
Roue support châssis | Amazon | | Vendu par 10 | 14,17 | https://www.amazon.fr/dp/B0BZZ3MNGG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

## 5.2 VOTRE PRÉ-SÉLECTION DE COMPOSANT (EEE)

Désignation | Fournisseur | Réf fournisseur | qte | Montant TTC | Lien internet
Moteur 57DMWH115-2440 | Gotronic | | 1 | 86,2 | https://www.gotronic.fr/art-moteur-57dmwh115-2440-37429.htm
Contrôleur de moteur CC sans balais numérique 12V-48VDC Max 15.0A 400W | Stepperonline | | 2 | 39,72 | https://www.omc-stepperonline.com/fr/controleur-de-moteur-cc-sans-balais-numerique-12v-48vdc-max-15-0a-400w-bld-510b
Module 9 dof | Gotronic | | 1 | 38,5 | https://www.gotronic.fr/art-module-9-dof-bno055-ada4646-33463.htm
Moteur BLDC | Stepperonline | | 1 | 24,85 | https://www.omc-stepperonline.com/fr/24v-3500rpm-0-23nm-84w-5-0a-f57x49mm-moteur-dc-sans-balais-57blr50-24-01

# 6 GESTION DE PROJET

## 6.1 EVALUATION DES RISQUES DU PROJET


## 6.2 AVANCEMENT DU PROJET (COURBE EN S)


Institut Catholiqued’Arts et Métiers 75, avenue de Grande-Bretagne, 31300 Toulouse http://icam.groupe-icam.fr

ICAM –F002 Page / Toute communication ou reproduction, même partielle, est strictement interdite sans autorisation écrite de l’ICAM

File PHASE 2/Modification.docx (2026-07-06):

Modifications demandées lors du 2e entretien

- Roues motrices moins arrondies pour + de contact
- Arrêt au dessus de la roue giratoire (au dessus des guidages par exemple)
- Le guidage de la giratoire ils ont parlé d’engrenage (éviter friction pour moins de problèmes) pcq ça va être compliqué notre solution (modifier constamment la distance des guidages)
- Le schéma conclusion n’est pas le bon
- Schéma damien pas bon, + en haut et masse en bas, vision physique
- mettre valeur puissance/tension
- Asservissement deuxième moteur ?
- Schéma avec composants électrique
- Accéléromètre que pour l’angle, pas de dérivation pour position
- Batterie pas en parallèle sinon composants en plus (24V vers 5V)
- 2 moteurs/2 drivers -> vérifier qu’on peut récupérer la position de l’encodeur
- Régulateur de tension (transistors), pas diviseur de tension
- Drivers -> isolation galvanique donc normalement pas de transistors

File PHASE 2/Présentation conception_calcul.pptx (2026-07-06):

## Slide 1

Fond de circuit blanc | Photo Premium

Projet BB-8

Conception

I. Vue d’ensemble du projet
II. Conception
III. Calculs
IV. Liste des composants
V. Conclusion

Groupe
I_Roue_6

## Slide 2


VUE D’ENSEMBLE

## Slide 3

CONCEPTION MÉCANIQUE


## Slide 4

CONCEPTION MÉCANIQUE


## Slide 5

CONCEPTION MÉCANIQUE


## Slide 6

CALCULS DIMENSIONNEMENT


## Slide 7

CALCULS DIMENSIONNEMENT


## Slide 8

LISTE DES COMPOSANTS


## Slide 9

CONCLUSION


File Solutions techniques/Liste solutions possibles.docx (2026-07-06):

Liste des solutions imaginées

- 1ère solution possible


L’un des principaux objectifs du système est que la commande soit plutôt précise afin que l’équilibrage du robot puisse être fait. Pour celà, nous avons pensé à un système de poulie courroie, s’inspirant du ControlX, qui est un système très rapide et plutôt précis.

Notre système est donc composé de 2 poulies libres ainsi qu’une poulie motrice qui sont toutes fixées au bâti. Ces 3 poulies sont toutes reliées par une courroie sur laquelle serait donc fixée une masse qui servira à l’équilibrage du robot.

Le principal inconvénient de cette solution réside dans la difficulté de fixer la masse à la courroie. De plus, le système est assez compliqué à mettre en place si nous voulons que la masse ait un déplacement complètement linéaire (courroie complètement tendue sans “ventres”).

- 2ème solution possible


Pour cette deuxième solution, nous avons dérivé vers un système de pignon crémaillère. La crémaillère serait donc immobile et fixée directement sur le bâti; et le pignon serait lui mobile le long de celle-ci. Le moteur est donc fixé sur le pignon ainsi que la masse. Dans ce système, la masse se déplace donc de gauche à droite en fonction de la commande exigée.

L’avantage de cette solution est que c’est assez précis mais l’inconvénient est surtout la difficulté de fabriquer une glissière et de fixer la masse à celle-ci. De plus, un autre point que nous avons pris en compte est également l’usure du pignon qui peut être important en fonction de la masse déplacée.

- 3ème solution possible


Cette solution est composée de 2 grandes parties différentes. Une première partie comporte un axe triangulaire mobile au bout duquel sont fixées 2 masses égales. La deuxième partie est quant à elle fixe et est reliée au bâti du robot. Cette partie comporte une roue motrice qui prend appui sur l’axe et le fait se déplacer par adhérence; ainsi que 4 roues folles qui permettent le bon guidage le long de l’axe ainsi que le maintien du contact entre la roue et l’axe.

Dans cette solution, nous avons trouvé beaucoup d’avantages, mais le seul problème qui persistait était le problème de l’encombrement horizontal, car nous voulions limiter au maximum celui-ci.

Nous sommes donc arrivés à cette dernière solution.

- 4ème solution possible Solution retenue


Pour cette dernière solution, vers laquelle nous nous orientons, nous avons décidé de garder le même système que la solution précédente (roue par adhérence). Néanmoins, sur cette solution, le support sur lequel sont fixées les masses est en forme d’arc de cercle. Celà permet d’être très précis sur la commande des masses tout en économisant de la place en envergure.

L’axe central mobile présentera donc une face plane du côté de la roue motrice ainsi que du côté des 4 roues folles. Les roues folles serviront donc à maintenir le contact entre la roue et l’arc de cercle ainsi que de guider le mouvement.

Les 2 masses sont égales et sont donc encastrées à chaque extrémité de l’axe.

Grâce à l’inclinomètre et à l’asservissement du robot, la commande se fera donc sur la roue motrice qui tournera dans le sens nécessaire pour orienter les masses.

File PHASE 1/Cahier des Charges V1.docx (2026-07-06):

PHASE1

CAHIER DES CHARGES

Groupe projet : 6

Robot roue type BB-8

SUIVI DES VERSIONS

Indice | Date | Modification | Approbation | Vérification | Rédaction
| | Modification n°1
A | 07/10/2024 | Création | | Laura | Laura/Rémi
| | | Nom Approb. | Nom Resp. | Nom Ingé.

LISTE DE DIFFUSION

Clients / Équipe | Nom
Produit/Projet | MAHOT Rémi
Conception | DAME Giovanni DECAUDIN Timothée
EEE | DEGUILHEM Damien
MIA | VACQUIE Lucas
Qualité | SEBASTIEN Laura
Achat/Fabrication | BARIC Clément

sommaire

1 GÉNÉRALITÉS 6

1.1 OBJECTIF 6

1.2 DONNÉES D’ENTRÉE 6

2 VEILLE SUR L’EXISTANT 7

2.1 PRODUITS EXISTANTS (avec liens internet) 7

2.2 TENDANCES – ÉVOLUTIONS 9

2.3 Synthèse DE VOTRE VEILLE 9

3 ENVIRONNEMENT DU PRODUIT 10

3.1 CONDITIONS D’UTILISATIONS 10

4 PISTES D’INNOVATIONS 11

4.1 VOS IDÉES EN VRAC ET EN NOMBRE 11

4.2 LES IDÉES RETENUES PAR L'ÉQUIPE PROJET 12

5 ANALYSE FONCTIONNELLE EXTERNE 13

5.1 APPROPRIATION DU BESOIN – REFORMULATION 13

5.2 EXPRESSION FONCTIONNELLE DU BESOIN 13

5.2.1 DIAGRAMME PIEUVRE 13

5.2.2 LISTE DES SPÉCIFICATIONS FONCTIONNELLES 14

6 ANALYSE FONCTIONNELLE INTERNE 16

6.1 DIAGRAMME FAST 16

6.2 ARCHITECTURE GÉNÉRALE DU système - SOUS-ENSEMBLES FONCTIONNELS 16

7 DOCUMENTATION SPÉCIFIQUE AU PROJET 17

7.1 Normes 17

7.2 AUTRES DOCUMENTS 17

glossaire

- Inclinomètre

Appareil mesurant la pente d'un terrain ou l'inclinaison d'un objet par rapport à un référentiel donné (souvent par rapport à la ligne d'horizon).

- Gyroscope

Un appareil constitué d'un disque dont l'axe de rotation est libre de prendre toutes les orientations possibles, mis en rotation autour d'un de ses axes principaux, celui-ci conserve son axe de rotation invariable. Ainsi, les gyroscopes sont utilisés comme capteur de position angulaire selon un ou deux axes uniquement.

1 GÉNÉRALITÉS
  1.1 OBJECTIF

L’objectif principal de notre projet est de développer un premier prototype fonctionnel de robot roue motorisée et pilotable à distance.

  1.2 DONNÉES D’ENTRÉE

Comme il s’agit d’un nouveau projet, nous possédons une certaine liberté dans nos choix de conception. Cependant, afin de répondre aux attentes du client, nous avons toutefois quelques contraintes à respecter.

Concernant la forme et les dimensions du robot, il s’agira d’une roue tronquée de 60 cm de diamètre et 30 cm d’épaisseur. Avec un diamètre de roue suffisamment grand, on peut obtenir rapidement la vitesse souhaitée et l’épaisseur de la roue nous permet d’obtenir l’équilibre nécessaire pour stabiliser le robot sans pour autant que cela nous impacte lors de ses rotations.

En effet, le robot doit pouvoir se déplacer dans l’espace en roulant. Pour cela, il doit savoir s’arrêter, avancer et reculer en ayant une vitesse moyenne de 3-4 km/h et un seuil maximal de 7 km/h. Il doit savoir aussi tourner dans toutes les directions ainsi que sur lui-même.

Pour réaliser cette action, on cherche à mettre en mouvement son centre de gravité et le faire déplacer le long de la roue.

Concernant la partie programmation du robot, il nous est imposé de coder en C ou C++ puisque nous devons utiliser des cartes ESP32. On utilisera notamment des moteurs précis et rapides afin que les déplacements de notre robot soient les plus fluides possibles. Pour que notre robot soit autonome, il faut qu’il dispose d’une batterie interne qu’on puisse recharger lui permettant de tenir deux heures en fonctionnement entre chaque rechargement.

Pour son utilisation, il doit être pilotable à partir d’une application de téléphone. Pour un accès au grand public, il suffira à l’utilisateur de scanner un QR code pour accéder au pilotage du robot.

2 VEILLE SUR L’EXISTANT
  2.1 PRODUITS EXISTANTS (avec liens internet)
- Robot D-0 inspiration star wars

https://youtu.be/zplirkxl6iM?si=WKp0uwwly6SlCgs7

Ce robot est une reproduction d’un robot de la saga star wars. Il a été réalisé en imprimante 3D. Son fonctionnement est basé sur deux roues qui s’apparentent en une seule et fonctionnent indépendamment. Ainsi, pour que le robot avance ou recule, il faut que les deux roues fonctionnent de manière synchronisée et aillent dans la même direction. Pour faire tourner une rotation, l’une des deux roues va avancer pendant que l’autre va reculer. Cette conception avantageuse permet donc au robot de pouvoir tourner sur lui-même.

Cette idée nous semblait être la meilleure pour réaliser le robot mais suite à notre entrevue avec le client, il nous a été imposé de réaliser un robot composé que d’une seule et même roue. Nous avons donc dû abandonner cette idée.


- Robot Gyroroue


La Gyroroue est composée d’un bâti qui est lié à une roue contrôlée par un moteur. Le bâti est donc à l'extérieur de la roue et ce sont les mouvements de l’utilisateur qui lui permettent de tourner (centre de gravité).

Nous gardons pour notre part l’idée de la rotation par centre de gravité.


- Ringbot

https://www.youtube.com/watch?v=DX3DMEreDyk

La particularité de ce robot est l’utilisation d’un système de stabilisation avancé pour maintenir l’équilibre sur une seule roue, similaire au fonctionnement d'un gyroscope.

Le Ringbot peut se déplacer en avant, en arrière, et même tourner sur lui-même en modifiant la vitesse de rotation de sa roue. Sa conception le rend agile et capable de se déplacer sur différents terrains tout en maintenant un équilibre stable.

Nous avons choisi de partir sur cette conception de roue avec un déplacement axial. Cependant, nous ne comptons pas recréer les bras dont il dispose pour se redresser.


  2.2 TENDANCES – ÉVOLUTIONS

Dans un premier temps, notre objectif principal est de réaliser un robot fonctionnel respectant le cahier des charges. Cependant, pour améliorer notre robot afin de le rendre plus autonome et performant, nous pouvons envisager plusieurs perspectives d’évolution qui sont les suivantes:

- Déplacement en milieu contraint (pluie, obstacle, sol granuleux)
- Augmentation de la vitesse
- Ajout d’un module de redressement lorsqu’il est à terre
- Ajout d’un détecteur d’obstacle d’abord à l’avant et à l’arrière du robot puis sur 360°
- Ajout d’une tête au robot
- Ajout d’une caméra sur la tête du robot qui retransmet l’image sur le téléphone de l’utilisateur
- Travail sur l’esthétisme
  2.3 Synthèse DE VOTRE VEILLE

Après avoir exploré plusieurs concepts de robots, trois modèles ont retenu notre attention : le robot D-0 de Star Wars, la Gyroroue, et le Ringbot.

Le D-0, fonctionnant par deux roues indépendantes, a été écarté en raison de la contrainte imposée par le client d'avoir une roue en une seule partie.

La Gyroroue, avec son mécanisme de contrôle par le centre de gravité, a inspiré la méthode de rotation du robot.

Finalement, le design du Ringbot, qui utilise une roue unique pour se déplacer tout en maintenant son équilibre, a été retenu.

Le choix final s'oriente vers un robot de type Ringbot, mais sans inclure les bras de stabilisation dans un premier temps, tout en apportant une solution différente.

3 ENVIRONNEMENT DU PRODUIT
  3.1 CONDITIONS D’UTILISATIONS

L’utilisation de notre robot se fera dans une salle fermée. Ainsi, nous n’avons pas de contraintes météorologiques à prendre en compte comme par exemple le vent ou les intempéries.

De plus, le robot roulera sur un sol adhérent qui sera une surface plane et lisse. Il n’aura aucun obstacle à éviter de lui-même.

Comme nous serons dans une salle fermée, ce sera à l’utilisateur de prendre en compte la distance qui sépare le robot des murs et de les éviter pour ne pas endommager le robot.

4 PISTES D’INNOVATIONS
  4.1 VOS IDÉES EN VRAC ET EN NOMBRE

On déplace notre masse sur les 3 axes dont un qui gère la direction et le reste sert pour le déplacement linéaire.

Rail interne

Contact par adhérence ou par engrenage

- Deux roues libres et une roue motorisée
- Une roue libre et deux roues motorisées

Masse latérale

Cette masse permet de faire pencher le robot pour le faire tourner. La commande dirige l’angle que doit suivre le robot pour tourner correctement via les capteurs.

- Poulie courroie (Contrôle X)
- Pignon crémaillère
- Vis sans fin
- Système du Max speed
- Même système que la roue du rail interne mis en perpendiculaire


Capteurs

- Inclinomètre
- Gyroscope
  4.2 LES IDÉES RETENUES PAR L'ÉQUIPE PROJET

Déplacement du robot

Le déplacement du robot se fait en modifiant la position du centre de masse. Cette solution permettra de faire avancer le robot linéairement mais servira aussi à le faire tourner. La masse principale (la plus massive) est utilisée pour contrôler la vitesse tandis qu'une deuxième appelée masse latérale aura comme seule mission de faire tourner le robot.

Équilibre

Notre robot doit être asservi pour pouvoir constamment garder l’équilibre, il doit ainsi déplacer son centre de masse à tout moment pour pouvoir pallier un déséquilibre inattendu.

Communication

L’utilisateur doit scanner un QR code positionné sur le robot pour pouvoir l’utiliser. Ce QR code connectera l’utilisateur au robot en le connectant au réseau wifi généré par la carte ESP 32. Pour assurer le bon fonctionnement du robot, la portée du signal doit couvrir une distance de 10m. A partir de l’application qui sera disponible sur IOS et Androïd, l’utilisateur pourra contrôler le robot grâce à un joystick permettant de gérer les déplacements, rotations et accélérations du robot.

5 ANALYSE FONCTIONNELLE EXTERNE
  5.1 APPROPRIATION DU BESOIN – REFORMULATION

Le but de ce projet est de concevoir et de créer un robot pouvant se déplacer dans toutes les directions y compris sur lui-même en roulant.

Pour son utilisation, le robot devra être pilotable par un utilisateur à travers une application de téléphone qui sera rendue accessible au grand public.

  5.2 EXPRESSION FONCTIONNELLE DU BESOIN
    5.2.1 DIAGRAMME PIEUVRE


    5.2.2 LISTE DES SPÉCIFICATIONS FONCTIONNELLES

Fonction | Critères de performance | Niveau de priorité (NP) | Niveau de conformité (NC) | Niveau de risque (NR) | Observations
FP1 Déplacement dans l’espace | Le robot doit pouvoir se déplacer dans l’espace et tourner sur lui même | 2 | 2 | 2 | Robot motorisé
FP2 Robot pilotable à distance | Le robot doit pouvoir être accessible et pilotable par le grand public | 2 | 2 | 2 | Application mobile sur IOS et Androïd
FC1 Dimensionnement | Le robot doit respecter les dimensions fixées | 1 | 1 | 1
FC2 Vitesse | Le robot doit atteindre une vitesse moyenne de 3-4 km/h et une vitesse maximale de 7 km/h | 1 | 1 | 2 | Moteurs rapides avec un couple important
FC3 Stabilité | Le robot doit s’équilibrer à l’aide des masses | 2 | 1 | 2 | Système en arc-de-cercle
FC4 Environnement | Le robot doit rouler sur une surface adhérente, plane et lisse | 2 | 1 | 1 | Pas de conditions météorologique à prendre en compte
FC5 Autonomie | Le robot doit pouvoir tenir 2h en fonctionnement | 1 | 2 | 1 | Batterie rechargeable
FC6 Technologie | Le robot doit fonctionner et être programmé en C ou C++ | 1 | 2 | 1 | Utilisation de carte ESP32

NP (Niveau de priorité)

- 0 : Faible
- 1 : Moyen
- 2 : Maximum

NC (Niveau de conformité)

- 0 : Non conforme
- 1 : Partiellement conforme
- 2 : Conforme

NR (Niveau de risque)

- 0 : Nul
- 1 : Moyen
- 2 : Majeur
6 ANALYSE FONCTIONNELLE INTERNE
  6.1 DIAGRAMME FAST


  6.2 ARCHITECTURE GÉNÉRALE DU système - SOUS-ENSEMBLES FONCTIONNELS


7 DOCUMENTATION SPÉCIFIQUE AU PROJET
  7.1 Normes
  7.2 AUTRES DOCUMENTS

Institut Catholiqued’Arts et Métiers 75, avenue de Grande-Bretagne, 31300 Toulouse http://icam.groupe-icam.fr

ICAM –F001 Page / Toute communication ou reproduction, même partielle, est strictement interdite sans autorisation écrite de l’ICAM

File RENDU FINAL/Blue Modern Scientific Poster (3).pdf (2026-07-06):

## Projet mécatronique I3

# PROJET I-ROUE6

# NOTRE ROBOT

Notre robot a plusieurs fonctionnalités; en effet, il peut avancer, reculer et même tourner sur lui-même grâce à la roue giratoire que nous avons créée.


## VITESSE DE 15 KM/H

Grâce à notre système
intégré dans la roue
permettant de rouler à
l’intérieur de celle-ci, nous arrivons à atteindre une
vitesse de pointe de 15 km/h.

## FACILE À CONTROLER DIRECTEMENT SUR TÉLÉPHONE

En scannant directement le QR-code, vous pouvez prendre les commandes du robot très facilement. Utilisez ensuite directement le joystick et les 2 boutons afin de pouvoir faire avancer et tourner le robot!

RETROUVEZ UNE VIDÉO DE
NOTRE ROBOT
EN SCANNANT CE QR-CODE !

## LÉGÈRETÉ ET FACILITÉ DE DÉMONTAGE


Grâce à sa conception
minimaliste, notre robot est très léger par rapport à sa taille. De plus, chaque
composant est facilement
démontable, notamment afin de pouvoir changer des pièces d’usure.

## TRÈS MANIABLE GRÂCE À SA CAPACITÉ DE ROTATION SUR LUI-MÊME

Grâce à la roue inertielle intégrée dans le châssis, le robot peut tourner à tout
moment et même à l’arrêt.

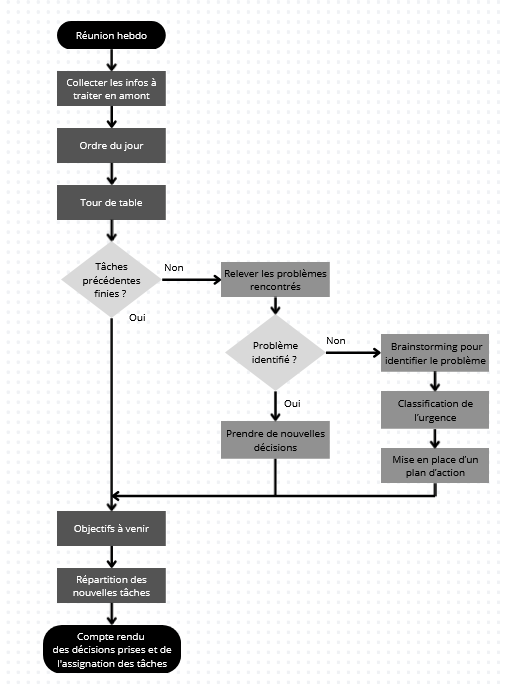
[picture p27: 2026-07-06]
Référent pôle/Qualité/Procédure/Procédure.PNG

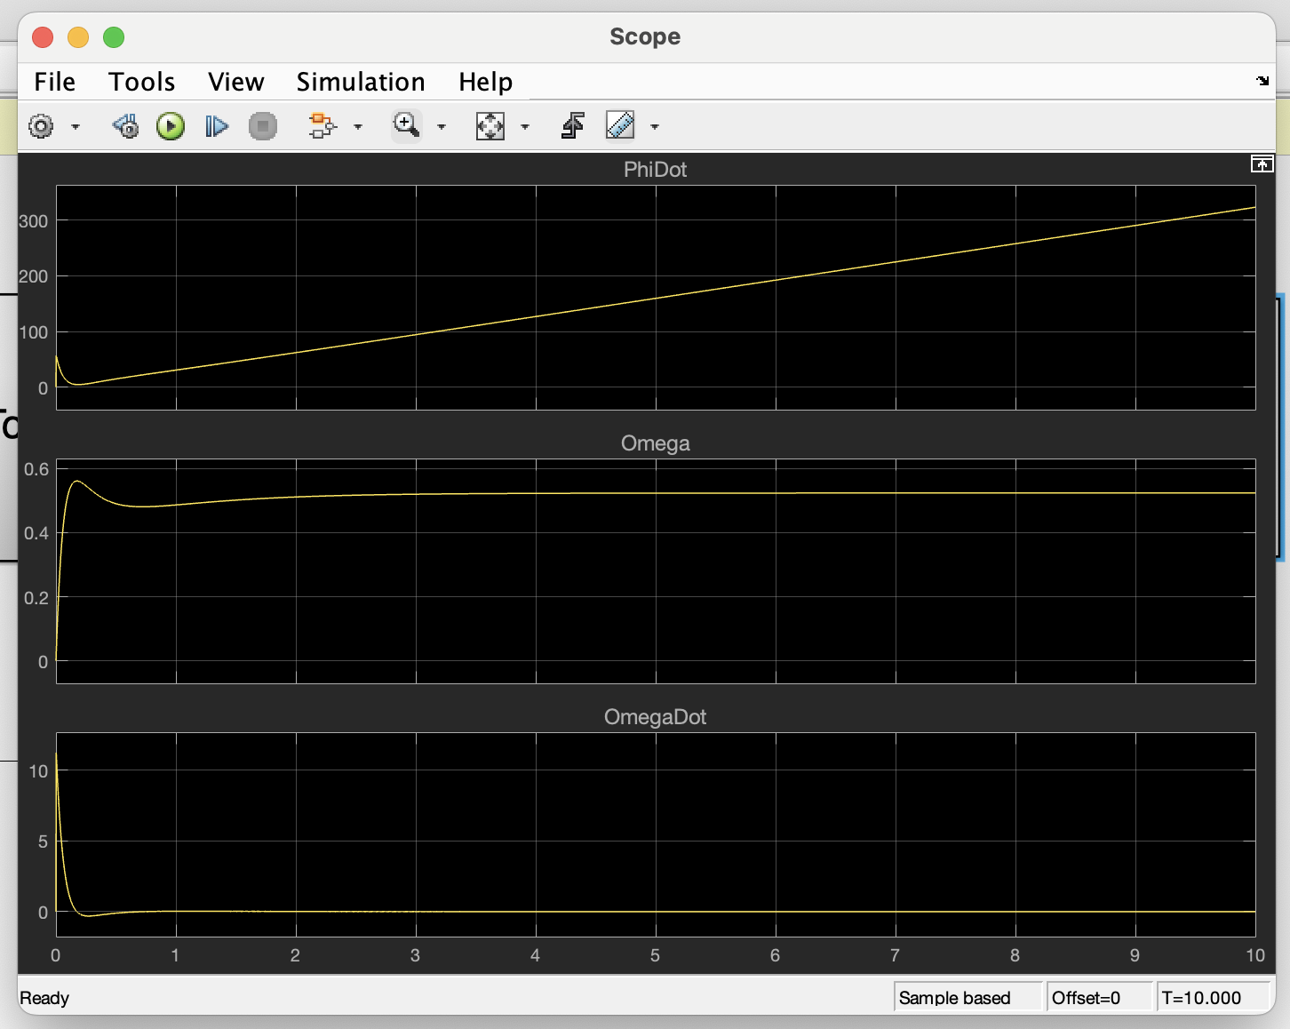
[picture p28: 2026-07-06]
Référent pôle/Matlab/Capture d’écran 2025-05-26 à 09.03.45.png

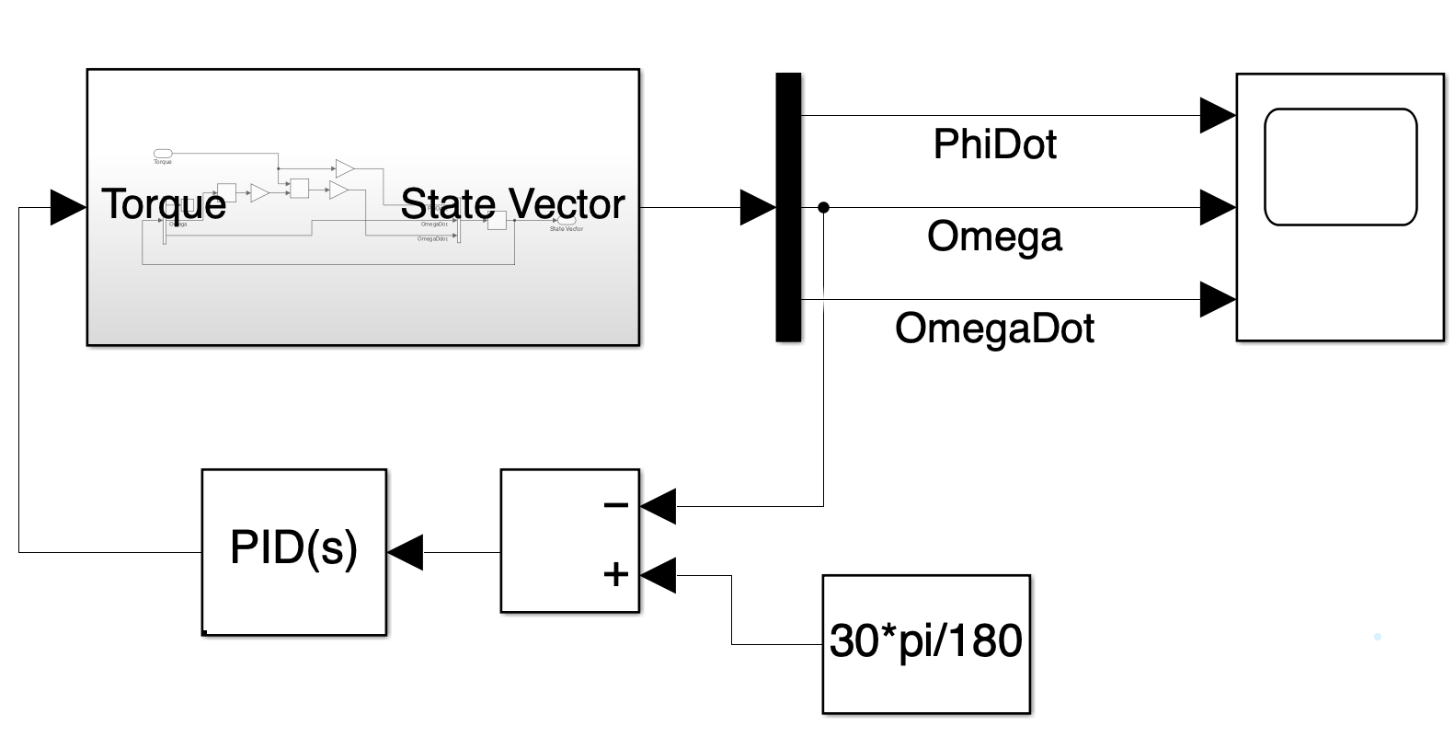
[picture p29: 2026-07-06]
Référent pôle/Matlab/Capture d’écran 2025-05-26 à 09.04.53.png

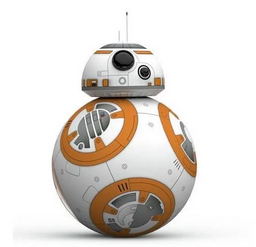
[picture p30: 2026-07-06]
Référent pôle/Programmation/Site Web Joystick/Version ordinateur/BB8.png

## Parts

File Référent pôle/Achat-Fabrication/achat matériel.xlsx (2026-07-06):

çr | Référence | Tr/min | Couple (en N.m) | tension (en V) | courant (en A) | Prix (en €)
2 | Moteur 57DMWH115-2440 - Gotronic (https://www.gotronic.fr/art-moteur-57dmwh115-2440-37429.htm) | 4000 | 0.5 | 24 | 12 | 86.2 | 1
2 | Contrôleur de moteur CC sans balais numérique 12V-48VDC Max 15.0A 400W - BLD-510B|STEPPERONLINE (https://www.omc-stepperonline.com/fr/controleur-de-moteur-cc-sans-balais-numerique-12v-48vdc-max-15-0a-400w-bld-510b) |  |  |  |  | 19.86 | 2
1 | Roue arrière 80mm Evo Primo : Amazon.fr (https://www.amazon.fr/Globber-Roue-arrire-80mm-Primo/dp/B07QGKGFHT?hvadid=80882915927285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) |  |  |  |  | 17.9
1 | Module 9 DoF BNO055 ADA4646 - Gotronic (https://www.gotronic.fr/art-module-9-dof-bno055-ada4646-33463.htm) |  |  |  |  | 38.5 | 1
 |  |  |  |  | Total | 268.52
 | Autre moteurs si problème:
2 | 24V 3500RPM 0.23Nm 84W 5.0A Ф57x49mm Moteur DC sans balais - 57BLR50-24-01|STEPPERONLINE (https://www.omc-stepperonline.com/fr/24v-3500rpm-0-23nm-84w-5-0a-f57x49mm-moteur-dc-sans-balais-57blr50-24-01) | 3500 | 0.23 | 24 | 5 | 24.85 | 1
1 | https://www.omc-stepperonline.com/fr/rapport-de-vitesse-de-boite-de-vitesses-planetaire-serie-mg-5-1-jeu-30arc-min-pour-moteur-pas-a-pas-nema-23-arbre-8mm-mg2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 |  |  |  |  | 29.09
 |  |  |  |  | Total | 174.91
1 | Uinfhyknd 10 pièces Roue en plastique avec roulements grands modèles roue ronde passive poulie folle roue pour CR10 3 : Amazon.fr: Auto et Moto (https://www.amazon.fr/dp/B0BZZ3MNGG?s=hi&sp_csd=d2lkZ2V0TmFtZT1zcF9kZXRhaWw)

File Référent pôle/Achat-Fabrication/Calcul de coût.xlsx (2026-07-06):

Nom | Quantité utilisée | Quantité commandée | Sous-ensemble | Lien | Coût unitaire HT | Coût unitaire TTC | Total HT | Total TTC | Date de commande | Quantité à commander
Roulement 1 bille | 8 | 12 | Roue inertielle (4) + Châssis (4) | CODIRATO 12 PCS Roulettes de Transfert avec Roulement à Billes Universels en Acier au Carbone Galvanisé Unité Roulettes à Billes Montées Charge Lourde pour Emballage Transmission Transpore Industrie : Amazon.fr (https://www.amazon.fr/CODIRATO-Roulettes-Transfert-Universels-Transmission/dp/B09XDNCL2L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) |  | 1.42 |  | 16.99 € | Commande 17/12 | 1
Roue support châssis | 4 | 10 | Châssis intérieur | Uinfhyknd 10 pièces Roue en plastique avec roulements grands modèles roue ronde passive poulie folle roue pour CR10 3 : Amazon.fr (https://www.amazon.fr/dp/B0BZZ3MNGG?s=hi&sp_csd=d2lkZ2V0TmFtZT1zcF9kZXRhaWw) |  | 1.42 |  | 14.17 € | Commande 17/12 | 1
Moteur 57DMWH115-2440 | 1 | 1 | Châssis + roue inertielle | Moteur 57DMWH115-2440 - Gotronic (https://www.gotronic.fr/art-moteur-57dmwh115-2440-37429.htm) | 71.83 | 86.2 | 71.83 | 86.20 € | Commande 17/12 | 1
Contrôleur de moteur CC sans balais numérique 12V-48VDC Max 15.0A 400W | 2 | 2 | Commande | Contrôleur de moteur CC sans balais numérique 12V-48VDC Max 15.0A 400W - BLD-510B|STEPPERONLINE (https://www.omc-stepperonline.com/fr/controleur-de-moteur-cc-sans-balais-numerique-12v-48vdc-max-15-0a-400w-bld-510b) |  | 19.86 |  | 39.72 € | Commande 17/12 | 2
Module 9 dof | 1 | 1 |  | Module 9 DoF BNO055 ADA4646 - Gotronic (https://www.gotronic.fr/art-module-9-dof-bno055-ada4646-33463.htm) |  | 38.5 |  | 38.50 € | Commande 17/12 | 1
Moteur BLDC | 1 | 1 |  | 24V 3500RPM 0.23Nm 84W 5.0A Ф57x49mm Moteur DC sans balais - 57BLR50-24-01|STEPPERONLINE (https://www.omc-stepperonline.com/fr/24v-3500rpm-0-23nm-84w-5-0a-f57x49mm-moteur-dc-sans-balais-57blr50-24-01) |  | 24.85 |  | 24.85 € | Commande 17/12 | 1
Roulement à billes à gorge profonde à une rangée RS PRO, ø int. 6mm, ø ext. 19mm, larg. 6mm | 8 | 8 | Rouleau guidage | https://fr.rs-online.com/web/p/roulements-a-billes/6189913?gb=s | 1.86 | 2.23 | 14.88 | 17.84 € | Trouvés Fablab
Frette de serrage épaulée autocentrante | 1 | 1 |  | https://shop.hpceurope.com/fr/produit.asp?prid=1192 |  | 21.87 |  | 21.87 € | 2025-03-11 | 1
PCB | 1 | 5 | commande |  |  | 5 |  | 5.00 €
Plaque PVC (plaque châssis) | 1 | 3 | châssis |  | 21.12333333 | 25.34666667 | 21.12333333 | 25.35 €
Barre en acier (diamètre 30) | 0.608 | 1 | Roue inertielle |  |  | 15 |  | 9.12 €
 |  |  |  |  |  |  | TOTAL | 299.61 €
IMPRESSION
NOM | MASSE (G) | QUANTITÉ | PRIX UNITAIRE | TEMPS | PRIX TOTAL | Temps total (hh:mm:ss)
lames 60° | 37.4 | 12 | 2.38 € | 0:50:00 | 28.56 € | 10:00:00
roue 30° | 244.43 | 12 | 4.89 € | 5:56:00 | 58.68 € | 71:12:00
châssis | 275.15 | 1 | 5.50 € | 7:45:00 | 5.50 € | 7:45:00
châssis sôcles | 182.9 | 1 | 3.66 € | 6:05:00 | 3.66 € | 6:05:00
support ext roulement amazon | 39.65 | 4 | 0.79 € | 2:00:00 | 3.16 € | 8:00:00
support roulement amazon (arbre) | 12.36 | 4 | 0.25 € | 0:33:00 | 1.00 € | 2:12:00
plaque adaptateur châssis (pcb) | 22.11 | 1 | 0.44 € | 1:25:00 | 0.44 € | 1:25:00
Têtes support moteurs | 40.25 | 2 | 0.40 € | 0:41:00 | 0.80 € | 1:22:00
Adaptateur moteur roue | 9.64 | 1 | 0.19 € | 0:27:00 | 0.19 € | 0:27:00
Rouleau guidage | 13.36 | 4 | 0.27 € | 0:33:00 | 1.08 € | 2:12:00
TOTAL |  |  |  |  | 103.07 € | 110:40:00
USINAGE
NOM | MATIÈRE PREMIÈRE | COÛT UTILISATION MACHINE (À L'HEURE) | TEMPS USINAGE | PRIX
Plaque châssis | 25.35 € | 30.00 € | 0:15:00 | 7.50 €
Masse roue inertielle | 9.12 € | 30.00 € | 1:30:00 | 45.00 €
TOTAL |  |  |  | 52.50 €
Coût total du projet
Achats | 299.61 €
Impressions 3D | 103.07 €
Usinage | 52.50 €
TOTAL | 455.18 €
Coût total avec la main d'oeuvre
Coût de revient | 455.18 €
Main d'oeuvre (980h) | 33320.00 €
TOTAL | 33775.18 €
MAIN D'OEUVRE
Nombre d'heures | 980
Coût de l'heure | 34.00 €
TOTAL | 33320.00 €

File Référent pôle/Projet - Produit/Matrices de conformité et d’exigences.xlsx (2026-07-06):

N° | Description des exigences | valeur de référence | Perf. atteint | Niveau de priorité | Validation OK/NON OK
1 | Le robot doit atteindre une vitesse moyenne et une vitesse maximale | Vitesse moyenne : 3-4 km/h Vitesse maximale : 7 km/h |  | Maximum |  | 4 | Non conformité totale à l'exigence
2 | Le robot doit pouvoir tourner sur lui-même même à l’arrêt | Rotation du robot : 12 tr/min |  | Maximum |  | 3 | Conformité d'environ 30% à l'exigence
3 | Le robot doit respecter les dimensions fixées | Diamètre: 60 cm Epaisseur: 30 cm |  | Moyen |  | 2 | Conformité d'environ 60% à l'exigence
4 | Le robot doit fonctionner sur batterie | Autonomie de 2h |  | Moyen |  | 1 | Conformité à 100% à l'exigence
5 | Le robot doit fonctionner et être programmé en C ou C++ |  |  | Moyen
6 | Le robot doit pouvoir être accessible et pilotable par le grand public |  |  | Maximum
7
8
9
10
11

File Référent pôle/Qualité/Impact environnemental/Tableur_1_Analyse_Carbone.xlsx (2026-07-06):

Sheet: Analyse Carbone
 |  |  |  | 0
 |  |  |  | kg équ. C
 |  | 0
 |  | kg équ. C
 |  |  |  |  |  | 0
 |  |  |  |  |  | kg équ. C
 | 0
 | kg équ. C |  | Total : | Total :
 |  |  | 0 | 0
 |  |  | kg équ. C | kg équ. CO2
 | 0
 | kg équ. C
 |  |  |  |  | 0
 |  |  |  |  | kg équ. C
 |  | CO2 émis par le cycle de vie du produit : |  |  |  | 0 | kg équ. CO2
 | Nombre de grands arbres nécessaires pour absorber une quantité équivalente de carbone en une année : |  |  |  |  | 0
 | Surface de forêt nécessaire pour absorber la même quantité de carbone en une année : |  |  |  |  | 0 | m2
ORDRE DE GRANDEUR D'EMISSION DE CO2 D'UN MENAGE Français
Un ménage français émet en moyenne 16,4 tonnes de CO2 par an. Il est, dans ses usages privés de l’énergie, directement reponsable d’une partie des émissions de CO2 dans l’atmosphère. Lorsqu’il utilise son véhicule pour se déplacer, lorsqu’il se chauffe, éclaire son logement, fait fonctionner ses appareils électroménagers, il participe clairement aux rejets de CO2 dans l’atmosphère.
SITES INTERNET POUR ALLER PLUS LOIN SUR LES SOLUTIONS DE REDUCTION D'EMISSIONS DE GAZ CARBONIQUE (CO2)
Site générations futures :
http://www.generationsfutures.com/compenser.html
Site Effet de serre :
http://www.effet2serre.com/index.htm
Site de V-GAS - Réalité virtuelle : un jeu pour contrôler son "empreinte carbone" :
http://alba.jrc.it/vgas/
Bibliothèque de V-GAS :
http://alba.jrc.it/vgas/virtualibrary/mainmenufr.swf

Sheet: Matières premières
Extraction et production de matières premières
 |  | Taux de recyclage | Masse | Facteurs d'emmision | Bilan Carbone
 | METAUX (moyennes) | % | kg | kg équ. C par kg | kg équ. C
 | Acier et métaux ferreux (seulement minerai d'extraction) | 0 |  | 0.87 | 0
 | Acier et métaux ferreux (recyclé à 100 %) | 100 |  | 0.3 | 0
 | Acier et métaux ferreux (extraction + recyclé à 50 %) | 50 |  | 0.585 | 0
 | Acier et métaux ferreux (extraction + recyclé à X %) |  |  | 0.87 | 0
 | Aluminium produit à partir de bauxite (extraction) | 0 |  | 2.89 | 0
 | Aluminium (recyclé à 100 %) | 100 |  | 0.67 | 0
 | Aluminium (extraction + recyclé à X %) |  |  | 2.89 | 0
 | Plomb |  |  | 0.57 | 0
 | Zinc |  |  | 0.8 | 0
 | Cuivre (laiton, bronze) |  |  | 0.8 | 0
 | Nickel |  |  | 2.5 | 0
 | PLASTIQUES (moyennes)
 | Polystyrène (PS) |  |  | 0.77 | 0
 | Polychlorure de vinyle (PVC) |  |  | 0.52 | 0
 | Acrylonitrile butadiène styrène (ABS - moyenne) |  |  | 1.4 | 0
 | Acrylonitrile butadiène styrène (ABS - recyclé à 100 %) | 100 |  | 0.8 | 0
 | Polypropylène haute densité (PP hd) |  |  | 0.5 | 0
 | Polypropylène haute densité (PP hd - recyclé à 100 %) | 100 |  | 0.25 | 0
 | Polypropylène basse densité (PP bd) |  |  | 0.55 | 0
 | Polypropylène basse densité (PP bd - recyclé à 100 %) | 100 |  | 0.23 | 0
 | Polyéthylène terephtalate (PET - amorphe) |  |  | 1.175 | 0
 | Polyéthylène terephtalate (PET - qualité bouteille) |  |  | 1.23 | 0
 | Polyéthylène terephtalate (PET - en film après transformation) |  |  | 1.6 | 0
 | Polyéthylène terephtalate (PET - moyenne) |  |  | 1.2 | 0
 | Polyéthylène terephtalate (PET - recyclé à 100 %) | 100 |  | 0.4 | 0
 | Epoxyde (EP - Epoxy) |  |  | 0.8 | 0
 | Polyamide (PA) |  |  | 2.08 | 0
 | Moyenne pour les plastiques |  |  | 0.64 | 0
 | VERRES (moyennes)
 | Verre bouteille |  |  | 0.28 | 0
 | Verre plat |  |  | 0.414 | 0
 | Laine de verre |  |  | 0.58 | 0
 | Verre recyclé (hors bouteilles) | 100 |  | 0.165 | 0
 | Moyenne pour les verres |  |  | 0.28 | 0
 | Verre technique |  |  | 1 | 0
 | Verre vert | 99 |  | 0.163 | 0
 | Verre brun | 61 |  | 0.213 | 0
 | Verre incolore | 55 |  | 0.209 | 0
 | PAPIERS ET CARTONS (moyennes)
 | Papier (papier journal, ramettes…) |  |  | 0.55 | 0
 | Carton |  |  | 0.5 | 0
 | Papier (essuie-tout, serviettes en papier) |  |  | 1.1 | 0
 |  |  | Masse |  | Bilan Carbone
 |  |  | Matières premières |  | Matières premières
 |  | Total : | 0 | Total : | 0
 |  |  | kg |  | kg équ. C
 |  | ratio : | #DIV/0!
 |  | kg équ. C / kg matières premières

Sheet: Energies fossiles
Energies fossiles (combustibles fossiles) [hors combustion]
 | Liées directement à la distribution (transports) | Masse | Volume | Facteurs d'emmision | Bilan Carbone
 | COMBUSTIBLES LIQUIDES | kg | litres | kg équ. C par kg | kg équ. C
 | (émissions provenant de l'extraction du pétrole brut, du raffinage à partir du pétrole brut, du stockage et du transport) [hors consommation (combustion) du produit fini]
 | Gaz de Pétrole Liquéfié (GPL) | 0 | 0 | 0.151 | 0
 | Essence (Supercarburant SP95, Supercarburant SP98) | 0 | 0 | 0.149 | 0
 | Gazole (diesel) | 0 | 0 | 0.092 | 0
 | Fioul domestique | 0 | 0 | 0.092 | 0
 | Fioul lourd | 0 | 0 | 0.117 | 0
 | Carburéacteur (Kérosène) | 0 | 0 | 0.079 | 0
 |  |  |  | Total : | 0
 |  | Masse | Volume | Facteur d'emmision | Bilan Carbone
 | COMBUSTIBLES GAZEUX | kg | m3 | kg équ. C par kg | kg équ. C
 | (émissions provenant de l'extraction, du traitement, du transport et des pertes du réseau de transport et de distribution) [hors consommation (combustion) du produit fini]
 | Gaz naturel | 0 | 0 | 0.099 | 0
 |  |  |  | Total : | 0
 |  | Masse |  | Facteurs d'emmision | Bilan Carbone
 | COMBUSTIBLES SOLIDES | kg |  | kg équ. C par kg | kg équ. C
 | (émissions provenant de l'énergie d'extraction, des fuites de CH4 (équ. CO2) et du transport) [hors consommation (combustion) du produit fini]
 | Charbon à coke (PCS>23 865 kJ/kg) | 0 |  | 0.058 | 0
 | Houille (PCS>23 865 kJ/kg) | 0 |  | 0.058 | 0
 | Charbon sous bitumeux (17 435 kJ/kg<PCS<23 865 kJ/kg) | 0 |  | 0.059 | 0
 | Agglomérés (provenant de houille ou sous bitumeux) | 0 |  | 0.071 | 0
 | Lignite (PCS<17 435 kJ/kg) | 0 |  | 0.04 | 0
 | Briquette de lignite | 0 |  | 0.039 | 0
 | Coke de houille | 0 |  | 0.07 | 0
 | Coke de lignite | 0 |  | 0.043 | 0
 | Coke de pétrole | 0 |  | 0.072 | 0
 | Tourbe | 0 |  | 0.03 | 0
 | Schistes | 0 |  | 0.023 | 0
 | Naphta | 0 |  | 0.077 | 0
 |  |  |  | Total : | 0
 |  |  |  |  | Bilan Carbone
 |  |  |  |  | Energies fossiles
 |  |  |  | Total : | 0
 |  |  |  |  | kg équ. C
Energies fossiles (combustibles fossiles) [avec combustion]
 |  | Masse | Volume | Facteurs d'emmision | Bilan Carbone
 | COMBUSTIBLES LIQUIDES | kg | litres | kg équ. C par kg | kg équ. C
 | (émissions provenant de l'extraction du pétrole brut, du raffinage à partir du pétrole brut, du stockage et du transport) [+ combustion du produit fini]
 | Gaz de Pétrole Liquéfié (GPL) |  | 0 | 0.954 | 0
 | Essence (Supercarburant SP95, Supercarburant SP98) |  | 0 | 1.025 | 0
 | Gazole (diesel) |  | 0 | 0.951 | 0
 | Fioul domestique |  | 0 | 0.951 | 0
 | Fioul lourd |  | 0 | 0.968 | 0
 | Carburéacteur (Kérosène) |  | 0 | 0.931 | 0
 |  |  |  | Total : | 0
 |  | Masse | Volume | Facteur d'emmision | Bilan Carbone
 | COMBUSTIBLES GAZEUX | kg | m3 | kg équ. C par kg | kg équ. C
 | (émissions provenant de l'extraction, du traitement, du transport et des pertes du réseau de transport et de distribution) [+ combustion du produit fini]
 | Gaz naturel |  | 0 | 0.87 | 0
 |  |  |  | Total : | 0
 |  | Masse |  | Facteurs d'emmision | Bilan Carbone
 | COMBUSTIBLES SOLIDES | kg |  | kg équ. C par kg | kg équ. C
 | (émissions provenant de l'énergie d'extraction, des fuites de CH4 (équ. CO2) et du transport) [+ combustion du produit fini]
 | Charbon à coke (PCS>23 865 kJ/kg) |  |  | 0.728 | 0
 | Houille (PCS>23 865 kJ/kg) |  |  | 0.728 | 0
 | Charbon sous bitumeux (17 435 kJ/kg<PCS<23 865 kJ/kg) |  |  | 0.735 | 0
 | Agglomérés (provenant de houille ou sous bitumeux) |  |  | 0.895 | 0
 | Lignite (PCS<17 435 kJ/kg) |  |  | 0.501 | 0
 | Briquette de lignite |  |  | 0.491 | 0
 | Coke de houille |  |  | 0.882 | 0
 | Coke de lignite |  |  | 0.541 | 0
 | Coke de pétrole |  |  | 0.905 | 0
 | Tourbe |  |  | 0.376 | 0
 | Schistes |  |  | 0.293 | 0
 | Naphta |  |  | 0.968 | 0
 |  |  |  | Total : | 0

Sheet: Fabrication
Fabrication des produits
 |  | Nombre de couches | Surface totale des cartes | Facteurs d'emmision | Bilan Carbone
 | PRODUCTION DES CARTES ELECTRONIQUES (moyennes) |  | cm² |  | kg équ. C
 | PCB (Printed Circuit Board) : circuit imprimé (pistes simple face) [dont Epoxy] | 1 |  | 0.002 | 0
 | PCB (Printed Circuit Board) : circuit imprimé (pistes double face) [dont Epoxy] | 2 |  | 0.004 | 0
 | PCB (Printed Circuit Board) : circuit imprimé (pistes multi-couches) [dont Epoxy] |  |  | 0 | 0
 | Composants électroniques (CMS) [dont matières premières] |  |  | 0.021 | 0
 | Composants électroniques (composants discrets) [dont matières premières] |  |  | 0.024 | 0
 |  |  |  | Total : | 0
 |  | Longueur | Section | Facteurs d'emmision | Bilan Carbone
 | FABRICATION DES FILS ET CABLES (moyennes) | cm | mm2 |  | kg équ. C
 | Câble ou fil 1 [dont matières premières] |  |  | 0.0288 | 0
 | Câble ou fil 2 [dont matières premières] |  |  | 0.0288 | 0
 | Câble ou fil 3 [dont matières premières] |  |  | 0.0288 | 0
 | Câble ou fil 4 [dont matières premières] |  |  | 0.0288 | 0
 | Câble ou fil 5 [dont matières premières] |  |  | 0.0288 | 0
 | Câble ou fil 6 [dont matières premières] |  |  | 0.0288 | 0
 | Câble ou fil 7 [dont matières premières] |  |  | 0.0288 | 0
 | Câble ou fil 8 [dont matières premières] |  |  | 0.0288 | 0
 | Câble ou fil 9 [dont matières premières] |  |  | 0.0288 | 0
 | Câble ou fil 10 [dont matières premières] |  |  | 0.0288 | 0
 | Câble ou fil 11 [dont matières premières] |  |  | 0.0288 | 0
 | Câble ou fil 12 [dont matières premières] |  |  | 0.0288 | 0
 |  |  |  | Total : | 0
 |  |  | Masse | Facteurs d'emmision | Bilan Carbone
 | FABRICATION DES ADAPTATEURS ELECTRIQUES (moyennes) |  | kg | kg équ. C par kg | kg équ. C
 | Adaptateur électrique 1 [dont matières premières] |  |  | 1.3 | 0
 | Adaptateur électrique 2 [dont matières premières] |  |  | 1.3 | 0
 | Adaptateur électrique 3 [dont matières premières] |  |  | 1.3 | 0
 | Adaptateur électrique 4 [dont matières premières] |  |  | 1.3 | 0
 |  |  |  | Total : | 0
 |  |  | Masse | Facteurs d'emmision | Bilan Carbone
 | MOULAGE DES PIECES MECANIQUES (moyennes) |  | kg | kg équ. C par kg | kg équ. C
 | Moulage toutes pièces en métal (hors aluminium) [hors matière première] |  |  | 0.8 | 0
 | Moulage toutes pièces en aluminium (ou zinc + aluminium) [hors matière première] |  |  | 0.6 | 0
 | Moulage toutes pièces en plastique [hors matière première] |  |  | 0.4 | 0
 |  |  |  | Total : | 0
 |  |  | Masse | Facteurs d'emmision | Bilan Carbone
 | FABRICATION DES PIECES MECANIQUES [hors pignons, roues, vis sans fin et roulements] (moyennes) |  | kg | kg équ. C par kg | kg équ. C
 | (usinage, pliage, emboutissage, découpage, soudage…)
 | Production pièces en métal (hors aluminium) [hors matière première] |  |  | 0.08 | 0
 | Production pièces en aluminium (ou zinc + aluminium) [hors matière première] |  |  | 0.04 | 0
 | Production pièces en plastique [hors matière première] |  |  | 0.0005 | 0
 |  |  |  | Total : | 0
 |  |  | Volume total des moteurs | Facteur d'emmision | Bilan Carbone
 | PRODUCTION DES MOTEURS ELECTRIQUES (moyenne) |  | cm3 |  | kg équ. C
 | Réalisation complète, bobinage, montage... [dont matières premières] |  |  | 0.005 | 0
 |  |  |  | Total : | 0
 |  | Nombre de dents ou filets | Diamètre primitif | Facteurs d'emmision | Bilan Carbone
 | PRODUCTION DES PIGNONS, ROUES ET VIS SANS FIN EN METAL (moyennes) |  | mm |  | kg équ. C
 | Pignon ou roue d'engrenage 1 [hors matières premières] |  |  | 5e-05 | 0
 | Pignon ou roue d'engrenage 2 [hors matières premières] |  |  | 5e-05 | 0
 | Pignon ou roue d'engrenage 3 [hors matières premières] |  |  | 5e-05 | 0
 | Pignon ou roue d'engrenage 4 [hors matières premières] |  |  | 5e-05 | 0
 | Pignon ou roue d'engrenage 5 [hors matières premières] |  |  | 5e-05 | 0
 | Pignon ou roue d'engrenage 6 [hors matières premières] |  |  | 5e-05 | 0
 | Pignon ou roue d'engrenage 7 [hors matières premières] |  |  | 5e-05 | 0
 | Pignon ou roue d'engrenage 8 [hors matières premières] |  |  | 5e-05 | 0
 | Pignon ou roue d'engrenage 9 [hors matières premières] |  |  | 5e-05 | 0
 | Pignon ou roue d'engrenage 10 [hors matières premières] |  |  | 5e-05 | 0
 | Pignon ou roue d'engrenage 11 [hors matières premières] |  |  | 5e-05 | 0
 | Pignon ou roue d'engrenage 12 [hors matières premières] |  |  | 5e-05 | 0
 | Pignon ou roue d'engrenage 13 [hors matières premières] |  |  | 5e-05 | 0
 | Pignon ou roue d'engrenage 14 [hors matières premières] |  |  | 5e-05 | 0
 | Pignon ou roue d'engrenage 15 [hors matières premières] |  |  | 5e-05 | 0
 | Pignon ou roue d'engrenage 16 [hors matières premières] |  |  | 5e-05 | 0
 | Pignon ou roue d'engrenage 17 [hors matières premières] |  |  | 5e-05 | 0
 | Pignon ou roue d'engrenage 18 [hors matières premières] |  |  | 5e-05 | 0
 | Pignon ou roue d'engrenage 19 [hors matières premières] |  |  | 5e-05 | 0
 | Pignon ou roue d'engrenage 20 [hors matières premières] |  |  | 5e-05 | 0
 | Pignon ou roue d'engrenage 21 [hors matières premières] |  |  | 5e-05 | 0
 | Pignon ou roue d'engrenage 22 [hors matières premières] |  |  | 5e-05 | 0
 | Pignon ou roue d'engrenage 23 [hors matières premières] |  |  | 5e-05 | 0
 | Pignon ou roue d'engrenage 24 [hors matières premières] |  |  | 5e-05 | 0
 | Pignon ou roue d'engrenage 25 [hors matières premières] |  |  | 5e-05 | 0
 | Pignon ou roue d'engrenage 26 [hors matières premières] |  |  | 5e-05 | 0
 | Pignon ou roue d'engrenage 27 [hors matières premières] |  |  | 5e-05 | 0
 | Pignon ou roue d'engrenage 28 [hors matières premières] |  |  | 5e-05 | 0
 | Pignon ou roue d'engrenage 29 [hors matières premières] |  |  | 5e-05 | 0
 | Pignon ou roue d'engrenage 30 [hors matières premières] |  |  | 5e-05 | 0
 | Pignon ou roue d'engrenage 31 [hors matières premières] |  |  | 5e-05 | 0
 | Pignon ou roue d'engrenage 32 [hors matières premières] |  |  | 5e-05 | 0
 | Couronne 1 [hors matières premières] |  |  | 0.00015 | 0
 | Couronne 2 [hors matières premières] |  |  | 0.00015 | 0
 | Vis sans fin 1 [hors matières premières] |  |  | 0.0004 | 0
 | Vis sans fin 2 [hors matières premières] |  |  | 0.0004 | 0
 | Vis sans fin 3 [hors matières premières] |  |  | 0.0004 | 0
 | Vis sans fin 4 [hors matières premières] |  |  | 0.0004 | 0
 |  |  |  | Total : | 0
 |  | Largeur | Diamètre | Facteurs d'emmision | Bilan Carbone
 | FABRICATION DES ROULEMENTS (moyennes) | cm | cm |  | kg équ. C
 | Roulement 1 |  |  | 0.005 | 0
 | Roulement 2 |  |  | 0.005 | 0
 | Roulement 3 |  |  | 0.005 | 0
 | Roulement 4 |  |  | 0.005 | 0
 | Roulement 5 |  |  | 0.005 | 0
 | Roulement 6 |  |  | 0.005 | 0
 | Roulement 7 |  |  | 0.005 | 0
 | Roulement 8 |  |  | 0.005 | 0
 | Roulement 9 |  |  | 0.005 | 0
 | Roulement 10 |  |  | 0.005 | 0
 | Roulement 11 |  |  | 0.005 | 0
 | Roulement 12 |  |  | 0.005 | 0
 | Roulement 13 |  |  | 0.005 | 0
 | Roulement 14 |  |  | 0.005 | 0
 | Roulement 15 |  |  | 0.005 | 0
 | Roulement 16 |  |  | 0.005 | 0
 | Roulement 17 |  |  | 0.005 | 0
 | Roulement 18 |  |  | 0.005 | 0
 | Roulement 19 |  |  | 0.005 | 0
 | Roulement 20 |  |  | 0.005 | 0
 |  |  |  | Total : | 0
 |  | Nombre d'éléments | Volume d'un élément | Facteurs d'emmision | Bilan Carbone
 | PRODUCTION DES BATTERIES, PILES, ACCUMULATEURS ... (moyennes) |  | cm3 |  | kg équ. C
 | Pile alcaline (non rechargeable) [dont matières premières] |  |  | 0.016 | 0
 | Pile saline carbone-zinc (non rechargeable) [dont matières premières] |  |  | 0.016 | 0
 | Pile lithium (non rechargeable) [dont matières premières] |  |  | 0.02 | 0
 | Accumulateur Ni-MH (Nickel-métal hydrure) rechargeable [dont matières premières] |  |  | 0.018 | 0
 | Accumulateur Ni-Cd (Nickel-cadmium) rechargeable [dont matières premières] |  |  | 0.018 | 0
 | Accumulateur Ni-Zn (Nickel-zinc) rechargeable [dont matières premières] |  |  | 0.018 | 0
 | Accumulateur Li-ion (Lithium ion) rechargeable [dont matières premières] |  |  | 0.02 | 0
 | Accumulateur Li-Po (Lithium polymère) rechargeable [dont matières premières] |  |  | 0.016 | 0
 | Batterie au plomb [dont matières premières] |  |  | 0.04 | 0
 |  |  |  | Total : | 0
 |  |  |  |  | Bilan Carbone
 |  |  |  |  | Fabrication
 |  |  |  | Total : | 0
 |  |  |  |  | kg équ. C
 | ORDRE DE GRANDEUR POUR LA FABRICATION D'UNE VOITURE
 | (matières premières comprises)
 | 1 tonne de voiture = 1,5 tonne équivalent carbone (équ. C)
 | ORDRE DE GRANDEUR POUR LA FABRICATION D'UN ORDINATEUR DE BUREAU A TUBE CATHODIQUE
 | (masse moyenne d'un ordinateur de bureau à tube cathodique : 28 kg)
 | Composants électroniques | 68.6
 | Circuit imprimé | 11.4
 | Tube cathodique | 7.5
 | Matériaux pour le boîtier de l'unité centrale | 17.4
 | Matériaux pour le boîtier de l'écran | 18.2
 | Production des produits chimiques | 48
 | Production des galettes de silicium | 14.8
 | Total : | 185.9
 |  | kg équ. C
 | ORDRE DE GRANDEUR POUR LA FABRICATION D'UN ORDINATEUR DE BUREAU A ECRAN PLAT
 | Composants électroniques | 68.6
 | Circuit imprimé | 11.4
 | Ecran plat | 184.3
 | Matériaux pour le boîtier de l'unité centrale | 17.4
 | Production des produits chimiques | 48
 | Production des galettes de silicium | 14.8
 | Total : | 344.5
 |  | kg équ. C

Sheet: Distribution
Distribution des produits
 |  | Moyenne du PTAC de la catégorie | Poids moyen à vide | Moyenne de la charge utile maximale | Moyenne de la durée de vie du véhicule | Impact de la fabrication du véhicule | Consommation moyenne du véhicule | Impact de la consommation du véhicule | Distance | Masse | Facteurs d'emmision | Bilan Carbone |  | Consommation d'essence | Consommation de diesel
 | TRANSPORT DE MARCHANDISES PAR CAMIONS OU CAMIONNETTES | tonnes | tonnes | tonnes | km | g équ. C/km | litres/100 km | g équ. C/km | km | kg | g équ. C par tonne.km | kg équ. C |  | kg | kg
 | (fabrication du véhicule + consommation du véhicule pour un pourcentage moyen de charge en Europe)
 | Classes de PTAC
 | < 1,5 tonnes essence | 1.3 | 0.9 | 0.4 | 150000 | 9 | 8.4 | 62.1 |  |  | 740.4 | 0 |  | 0
 | < 1,5 tonnes diesel | 1.3 | 0.9 | 0.4 | 200000 | 6.8 | 7.2 | 58.6 |  |  | 680.8 | 0 |  |  | 0
 | 1,5 à 2,5 tonnes essence | 1.8 | 1.1 | 0.7 | 150000 | 11 | 9.5 | 70.2 |  |  | 483.4 | 0 |  | 0
 | 1,5 à 2,5 tonnes diesel | 1.8 | 1.1 | 0.7 | 200000 | 8.3 | 8.4 | 68.4 |  |  | 456.1 | 0 |  |  | 0
 | 2,51 à 3,5 tonnes essence | 2.9 | 1.7 | 1.2 | 200000 | 12.8 | 16.7 | 123.4 |  |  | 472.8 | 0 |  | 0
 | 2,51 à 3,5 tonnes diesel | 2.9 | 1.7 | 1.2 | 250000 | 10.2 | 10.8 | 87.9 |  |  | 340.7 | 0 |  |  | 0
 | 3,5 tonnes | 3.5 | 2.1 | 1.4 | 300000 | 10.5 | 12.4 | 100.9 |  |  | 331.7 | 0 |  |  | 0
 | 3,51 à 5 tonnes | 4.74 | 2.37 | 2.37 | 300000 | 11.9 | 18.5 | 150.6 |  |  | 285.4 | 0 |  |  | 0
 | 5,1 à 6 tonnes | 5.67 | 2.84 | 2.83 | 300000 | 14.2 | 14.5 | 118 |  |  | 194.2 | 0 |  |  | 0
 | 6,1 à 10,9 tonnes | 8.8 | 4.11 | 4.69 | 380000 | 16.2 | 21.9 | 178.3 |  |  | 145.1 | 0 |  |  | 0
 | 11 à 19 tonnes | 16.32 | 6.53 | 9.79 | 480000 | 20.4 | 29.6 | 240.9 |  |  | 74.9 | 0 |  |  | 0
 | 19,1 à 21 tonnes | 19.37 | 7.75 | 11.62 | 550000 | 21.1 | 34.2 | 278.4 |  |  | 71.4 | 0 |  |  | 0
 | 21,1 à 32,6 tonnes | 26.87 | 10.21 | 16.66 | 650000 | 23.6 | 42.8 | 348.4 |  |  | 64.1 | 0 |  |  | 0
 | Tracteurs routiers (ensembles articulés - "semi-remorques") | 40 | 15 | 25 | 750000 | 30 | 37.1 | 302 |  |  | 29.4 | 0 |  |  | 0
 |  |  |  |  |  |  |  |  |  |  | Total : | 0 | Total : | 0 | 0
 | Calcul des distances routières en Europe : |  |  |  |  |  |  |  |  |  |  |  | Total : | 0 | 0
 | www.viamichelin.fr |  |  |  |  |  |  |  |  |  |  |  |  | tonnes | tonnes
 | www.mappy.fr
 | www.infotrafic.fr
 |  | Catégorie | Quantité maximale de carburant | Autonomie (pour la charge emportée) | Fret | Distance | Masse | Facteurs d'emmision | Bilan Carbone |  |  | Consommation de Kérosène
 | TRANSPORT AERIEN DE MARCHANDISES |  | litres | km | tonnes | km | kg | kg équ. C par tonne.km | kg équ. C |  |  | kg
 | (hors fabrication de l'avion)
 | Type d'avion
 | Airbus A318 | Court-courrier | 23860 | 2778 | 16 |  |  | 1.044 | 0 |  |  | 0
 | Airbus A318 | Court-courrier | 23860 | 5186 | 10 |  |  | 0.895 | 0 |  |  | 0
 | Airbus A319 | Court-courrier | 29660 | 4593 | 18.5 |  |  | 0.68 | 0 |  |  | 0
 | Airbus A319 | Court-courrier | 29660 | 6852 | 11 |  |  | 0.765 | 0 |  |  | 0
 | Airbus A320 | Court-courrier | 29660 | 2675 | 20 |  |  | 1.078 | 0 |  |  | 0
 | Airbus A320 | Court-courrier | 29660 | 4116 | 15 |  |  | 0.934 | 0 |  |  | 0
 | Airbus A300F | Moyen-courrier | 68150 | 5062 | 52 |  |  | 0.504 | 0 |  |  | 0
 | Airbus A300F | Moyen-courrier | 68150 | 6297 | 43 |  |  | 0.49 | 0 |  |  | 0
 | Airbus A310 | Moyen-courrier | 75470 | 6482 | 33 |  |  | 0.689 | 0 |  |  | 0
 | Airbus A330-200 | Long-courrier | 139090 | 8149 | 104 |  |  | 0.319 | 0 |  |  | 0
 | Airbus A330-200 | Long-courrier | 139090 | 11112 | 68 |  |  | 0.358 | 0 |  |  | 0
 | Airbus A340-600 | Long-courrier | 194880 | 10371 | 147 |  |  | 0.248 | 0 |  |  | 0
 | Airbus A340-600 | Long-courrier | 194880 | 13890 | 80 |  |  | 0.341 | 0 |  |  | 0
 | Airbus A380 | Long-courrier | 310000 | 10408 | 150 |  |  | 0.386 | 0 |  |  | 0
 | Boeing B747-400 | Long-courrier | 216840 | 13446 | 113 |  |  | 0.278 | 0 |  |  | 0
 |  |  |  |  |  |  |  | Total : | 0 |  | Total : | 0
 | Calcul des trajets aériens : |  |  |  |  |  |  |  |  |  | Total : | 0
 | pour la détermination des codes IATA des aéroports : |  |  |  |  |  |  |  |  |  |  | tonnes
 | www.amadeus.net
 | www.abm.fr/avion/gvacodapt.html
 | pour le calcul des distances entre aéroports à partir des codes IATA ou des noms de villes :
 | http://landings.com/_landings/pages/search/rel-calc.html
 | www.levoyageur.net/distan.php
 |  | Distance | Masse | Facteurs d'emmision | Bilan Carbone
 | TRANSPORT FERROVIAIRE DE FRET EN EUROPE | km | kg | kg équ. C par tonne.km | kg équ. C
 | Consommation énergétique pour la traction des trains [% diesel + % électrique compris] et tient compte de la manière dont le pays produit son électricité) (hors fabrication des infrastructures et hors fabrication du matériel roulant)
 | Pays
 | Allemagne |  |  | 0.0087 | 0
 | Autriche |  |  | 0.0034 | 0
 | Belgique |  |  | 0.0051 | 0
 | Bulgarie |  |  | 0.0186 | 0
 | Danemark |  |  | 0.0103 | 0
 | Espagne |  |  | 0.0094 | 0
 | Estonie |  |  | 0.0142 | 0
 | Finlande |  |  | 0.0055 | 0
 | France |  |  | 0.002 | 0
 | Hongrie |  |  | 0.0092 | 0
 | Grèce |  |  | 0.0121 | 0
 | Irlande |  |  | 0.0159 | 0
 | Italie |  |  | 0.0079 | 0
 | Lettonie |  |  | 0.0181 | 0
 | Lituanie |  |  | 0.0176 | 0
 | Luxembourg |  |  | 0.0069 | 0
 | Norvège |  |  | 0.0022 | 0
 | Pays-Bas |  |  | 0.0083 | 0
 | Pologne |  |  | 0.0179 | 0
 | Portugal |  |  | 0.0121 | 0
 | République Tchèque |  |  | 0.0132 | 0
 | Roumanie |  |  | 0.0188 | 0
 | Royaume-Uni |  |  | 0.0112 | 0
 | Slovaquie |  |  | 0.0134 | 0
 | Slovénie |  |  | 0.0114 | 0
 | Suède |  |  | 0.0012 | 0
 | Suisse |  |  | 0.001 | 0
 |  |  |  | Total : | 0
 | Calcul des distances ferroviaires en Europe :
 | (hypothèse de distances sensiblement identiques aux distances routières)
 | www.viamichelin.fr
 | www.mappy.fr
 | www.infotrafic.fr
 |  | Capacité | Vitesse commerciale | Vitesse commerciale | Consommation en mer de fioul lourd | Consommation tertiaire de gasoil | Parcours quotidien | Durée du trajet | Distance | Distance | Volume | Emissions par jour de mer | Bilan Carbone |  | Consommation de fioul lourd | Consommation de diesel
 | TRANSPORT MARITIME DE MARCHANDISES | m3 | nœuds | km/h | tonnes/jour | tonnes/jour | km | jours | km | Mille Marin | m3 | tonnes équ. C | kg équ. C |  | kg | kg
 | (consommation énergétique) (hors fabrication des navires car négligeable par rapport à la consommation) |  |  |  |  |  |  |  |  | Nautical Miles
 | Porte-conteneurs : capacité "équivalent vingt pied (evp)"
 | (équivalent au nombre de conteneurs car 20 pieds = 6 m = la longueur d'un conteneur donc 1 evp = 6 x 2,44 (largeur) x 2,5 (hauteur) = 36,6 m3)
 | 500 (evp ou conteneurs) | 18300 | 16 | 29.632 | 20 | 1.5 | 711 | 0 | 0 |  |  | 21.5 | 0 |  | 0 | 0
 | 1000 | 36600 | 17.5 | 32.41 | 30 | 1.5 | 778 | 0 | 0 |  |  | 31.5 | 0 |  | 0 | 0
 | 1500 | 54900 | 20 | 37.04 | 50 | 2 | 889 | 0 | 0 |  |  | 52 | 0 |  | 0 | 0
 | 2500 | 91500 | 20.5 | 37.966 | 70 | 2 | 911 | 0 | 0 |  |  | 72 | 0 |  | 0 | 0
 | 3500 | 128100 | 22.5 | 41.67 | 110 | 2 | 1000 | 0 | 0 |  |  | 112 | 0 |  | 0 | 0
 | 5000 | 183000 | 22.5 | 41.67 | 150 | 3 | 1000 | 0 | 0 |  |  | 153 | 0 |  | 0 | 0
 |  |  |  |  |  |  |  |  |  |  |  | Total : | 0 | Total : | 0 | 0
 | Calcul de la distance du trajet entre les ports (en mille marin) : |  |  |  |  |  |  |  |  |  |  |  |  | Total : | 0 | 0
 | (prise en compte, bien entendu, du contournement des continents) |  |  |  |  |  |  |  |  |  |  |  | Bilan Carbone |  | tonnes | tonnes
 | www.distances.com |  |  |  |  |  |  |  |  |  |  |  | Distribution
 |  |  |  |  |  |  |  |  |  |  |  | Total : | 0
 |  |  |  |  |  |  |  |  |  |  |  |  | kg équ. C

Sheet: Utilisation du produit
Utilisation des produits
 |  | Consommation annuelle | Durée de vie | Consommation journalière | Facteurs d'emmision | Bilan Carbone
 | CONSOMMATION ELECTRIQUE LORS DE L'UTILISATION (MOYENNES) | kWh | années | Wh | kg équ. C par kWh | kg équ. C
 | (bilan de la consommation électrique sur la durée de vie totale du produit suivant le pays)
 | Pays
 | Allemagne | 0 |  |  | 0.141 | 0
 | Autriche | 0 |  |  | 0.056 | 0
 | Belgique | 0 |  |  | 0.073 | 0
 | Danemark | 0 |  |  | 0.091 | 0
 | Espagne | 0 |  |  | 0.117 | 0
 | Finlande | 0 |  |  | 0.069 | 0
 | France | 0 |  |  | 0.023 | 0
 | Grèce | 0 |  |  | 0.222 | 0
 | Irlande | 0 |  |  | 0.176 | 0
 | Italie | 0 |  |  | 0.139 | 0
 | Luxembourg | 0 |  |  | 0.083 | 0
 | Pays-Bas | 0 |  |  | 0.12 | 0
 | Portugal | 0 |  |  | 0.137 | 0
 | Royaume-Uni | 0 |  |  | 0.124 | 0
 | Suède | 0 |  |  | 0.012 | 0
 | Moyenne européenne | 0 |  |  | 0.096 | 0
 | USA | 0 |  |  | 0.158 | 0
 | Japon | 0 |  |  | 0.115 | 0
 |  |  |  |  | Total : | 0
 | ORDRES DE GRANDEUR DE CONSOMMATIONS ELECTRIQUES DE DIFFERENTS APPAREILS EN France | Consommation annuelle moyenne | Durée de vie | Bilan Carbone |  | Bilan Carbone
 |  | kWh | années | kg équ. C |  | Utilisation du produit
 | Appareil |  |  |  | Total : | 0
 | Réfrigérateur | 365 |  | 0 |  | kg équ. C
 | Réfrigérateur-congélateur | 600 |  | 0
 | Congélateur | 615 |  | 0
 | Congélateur américain | 1640 |  | 0
 | Lave-linge | 250 |  | 0
 | Lave-vaisselle | 285 |  | 0
 | Sèche-linge | 430 |  | 0
 | TV | 160 |  | 0
 | Magnétoscope | 122 |  | 0
 | Décodeur Canal+ | 96 |  | 0
 | Démodulateur d'antenne parabolique | 80 |  | 0
 | HiFi | 35 |  | 0
 | Répondeur téléphonique | 25 |  | 0
 | Téléphone répondeur | 45 |  | 0
 | Téléphone sans fil | 23 |  | 0
 | Aspirateur | 18 |  | 0
 | Eclairage | 465 |  | 0
 | Lampe halogène | 292 |  | 0
 | Fer à repasser | 40 |  | 0
 | Aquarium à poissons exotiques | 800 |  | 0
 | Chaudière murale mal asservie | 400 |  | 0
 | Pompe de piscine | 1500 |  | 0
 | Ventillation mécanique contrôlée individuelle | 311 |  | 0
 | Totalité des consommations électriques en cuisine | 568 |  | 0
 | Four de cuisine | 224 |  | 0
 | Cuisinière | 457 |  | 0
 | Plaques vitrocéramique | 281 |  | 0
 | Table à induction | 337 |  | 0
 | Plaques de cuisson (toutes types confondus) | 273 |  | 0
 | Micro-ondes | 60 |  | 0
 | Mini-four | 99 |  | 0
 | Cafetière | 31 |  | 0
 | Bouilloire | 58 |  | 0
 | Friteuse | 11 |  | 0
 | Grille-pain | 14 |  | 0
 | Cuiseur vapeur | 15 |  | 0
 |  |  | Total : | 0
 |  | Production | Facteurs d'emmision | Bilan Carbone
 | EMISSIONS DE L'EOLIEN ET DU PHOTOVOLTAIQUE | kWh | kg équ. C par kWh | kg équ. C
 | (émissions en fonction de l'analyse du cycle de vie (ACV)) [fabrication comprise]
 | Type
 | Eoliennes |  | 0.002 | 0
 | Panneaux photovoltaIques |  | 0.015 | 0
 |  |  | Total : | 0
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

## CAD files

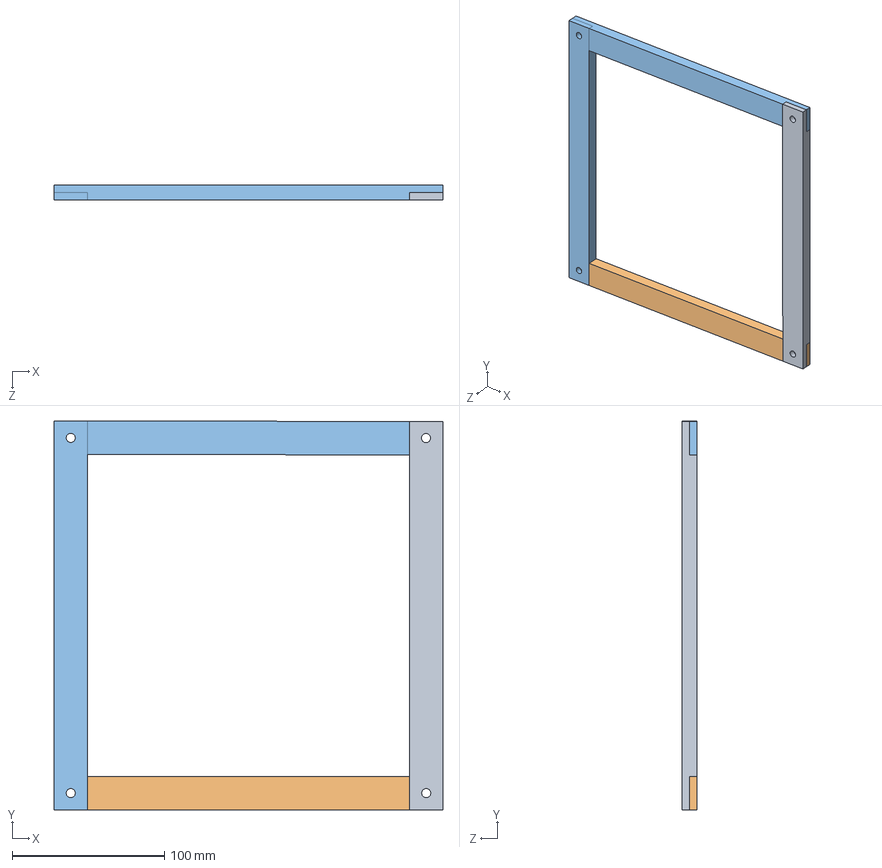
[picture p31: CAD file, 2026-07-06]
Solidworks/4- Assemblages/7- assemblage maintien.SLDASM
255.5 x 255.4 x 10.0 mm
7 - maintien Ri x 2
7 - maintien RI2
7 - maintien RI3

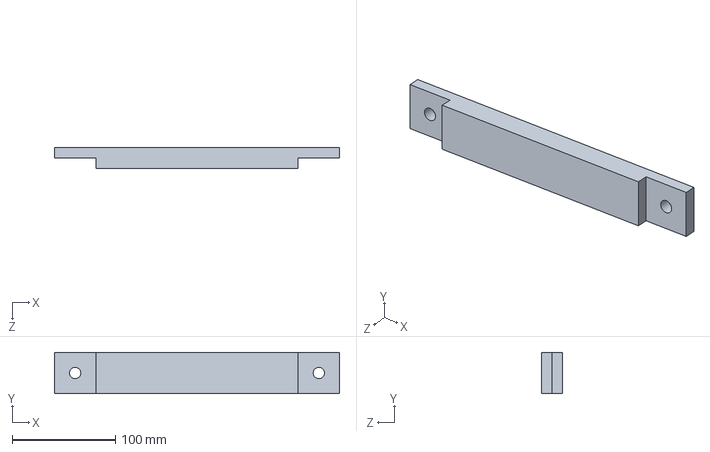
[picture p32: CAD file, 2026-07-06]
Solidworks/3- Roue inertielle/7 - maintien ouest-nord.SLDPRT
276.0 x 40.0 x 20.0 mm

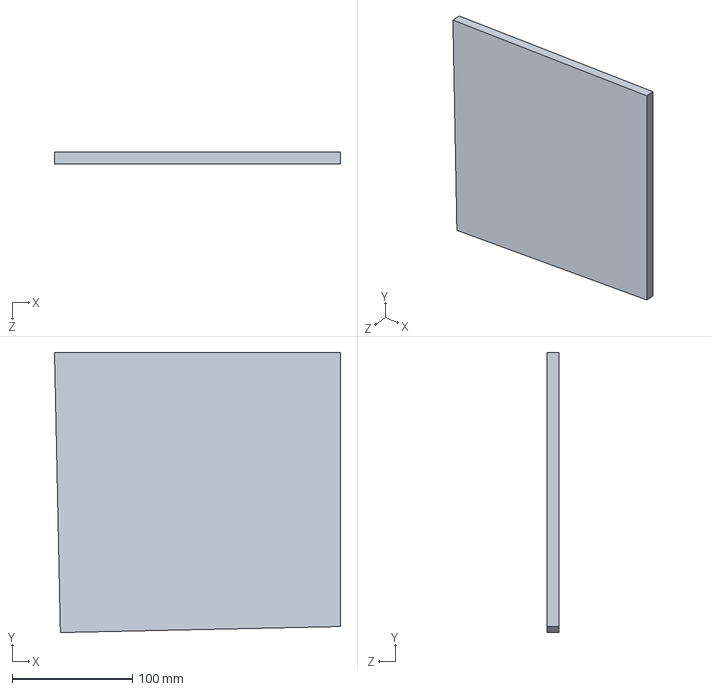
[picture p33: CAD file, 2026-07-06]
Solidworks/3- Roue inertielle/7 - maintien roue inertielle.SLDPRT
238.2 x 233.4 x 10.0 mm

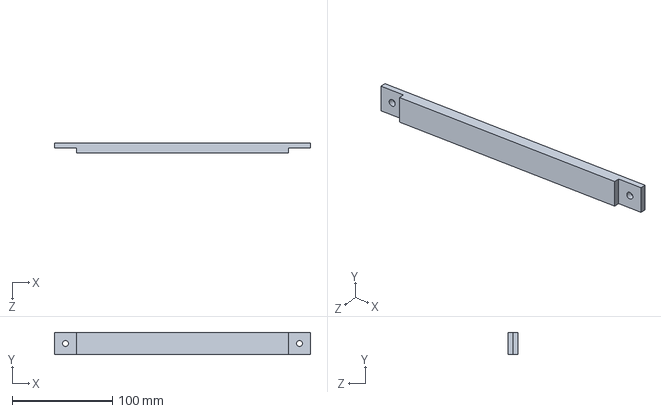
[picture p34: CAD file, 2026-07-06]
Solidworks/3- Roue inertielle/7 - maintien RI2.SLDPRT
255.5 x 22.0 x 10.0 mm

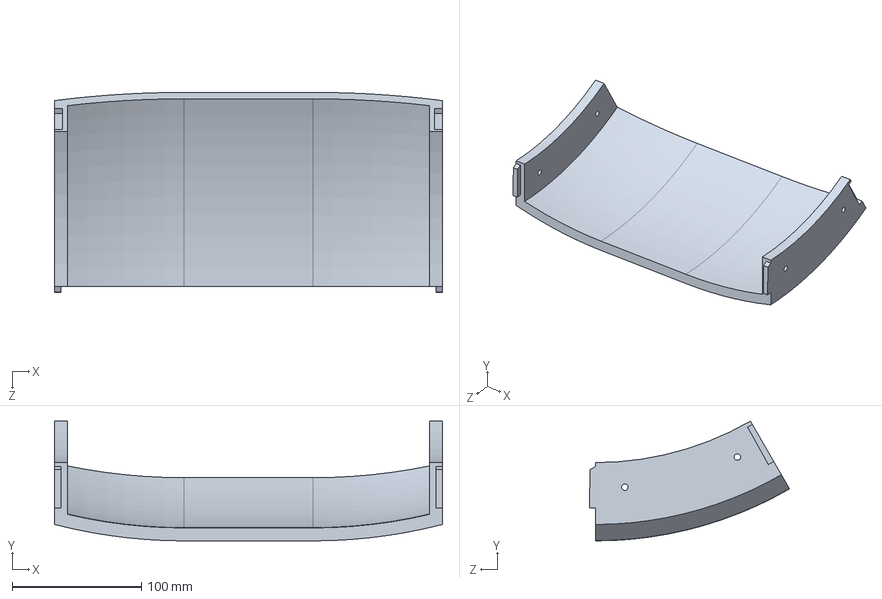
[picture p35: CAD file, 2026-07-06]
Solidworks/1- Roue/1- Roue 30deg.SLDPRT
300.0 x 92.6 x 154.8 mm

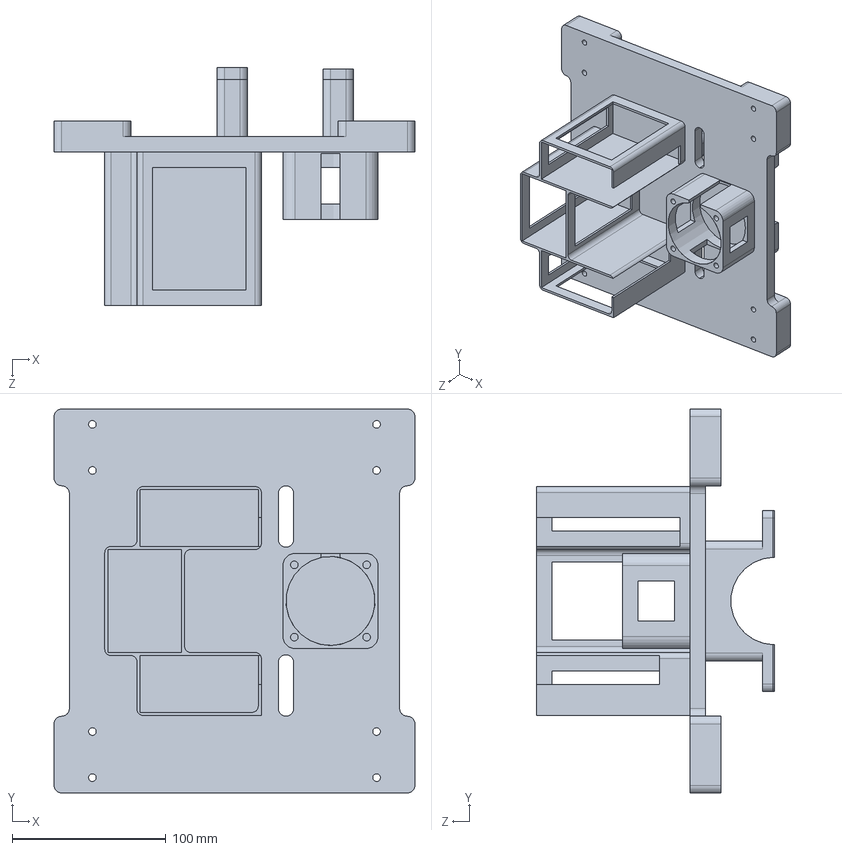
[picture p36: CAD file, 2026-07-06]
Solidworks/2- Chassis/6- chassis.SLDPRT
235.0 x 250.0 x 155.0 mm

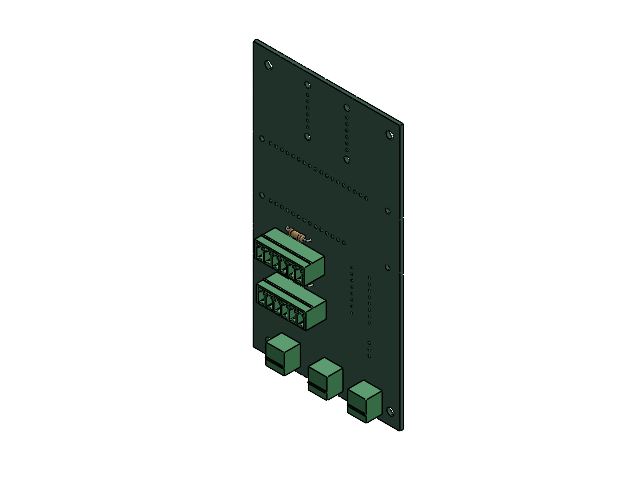
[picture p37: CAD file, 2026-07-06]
Solidworks/3- Roue inertielle/7- PCB (RI6VF).SLDASM
MC_01x02_G_3_5mm.step x 3
R_Axial_DIN0207_L63mm_D25mm_P1016mm_Horizontal.step x 2
MCV_01x06_G_3_5mm.step x 2
RI6VF_PCB.step

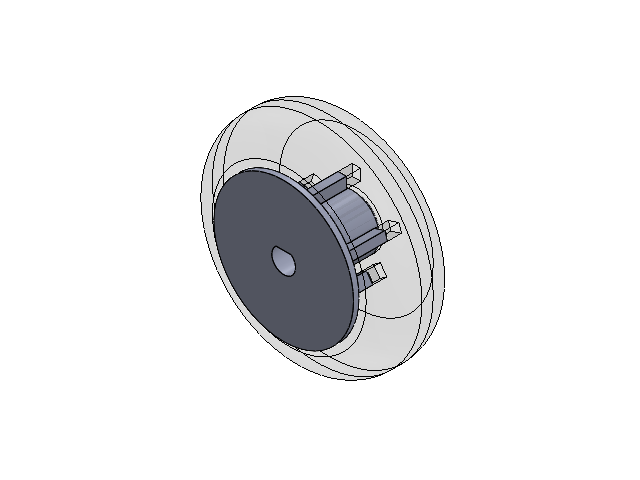
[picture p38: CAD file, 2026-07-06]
Solidworks/4- Assemblages/6 - assemblage adaptateur + roue inertielle moteur.SLDASM
7 - adaptateur moteur roue
7- roue motrice inertielle

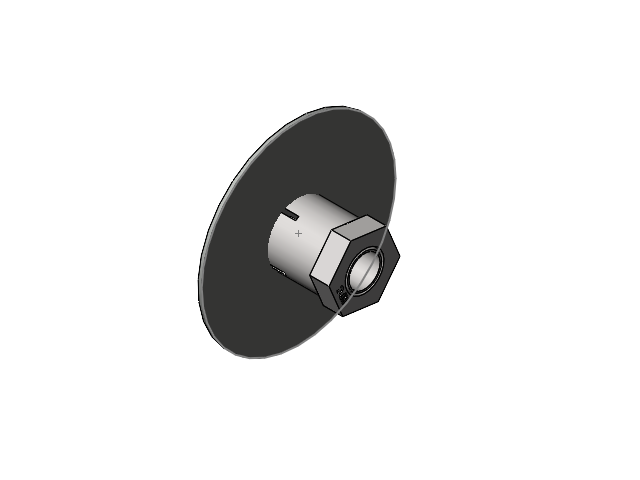
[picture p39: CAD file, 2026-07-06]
Solidworks/2- Chassis/6- hpc_SUP-008_SS.sldasm
6 - adaptateur HPC - SUP008
hpc_SUP-008_SS_1
hpc_SUP-008_SS_2
hpc_SUP-008_SS_3

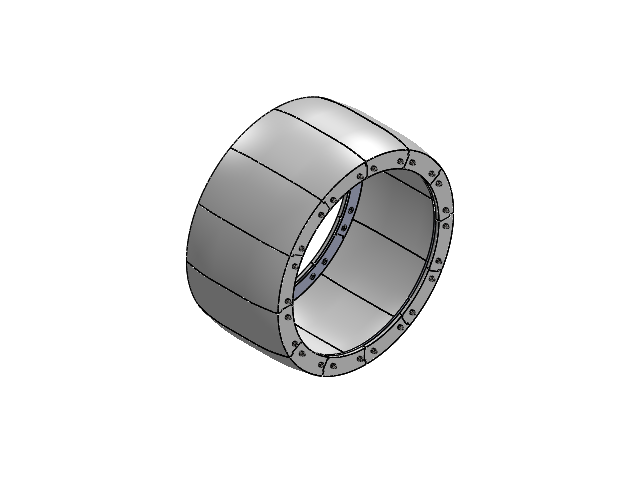
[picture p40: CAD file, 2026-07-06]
Solidworks/4- Assemblages/1- assemblage roue + lame.SLDASM
1- Roue 30deg x 12
1- Lame 60deg x 12
hexa csunk flathd screw_iso x 48
hex nut gradec_iso x 48

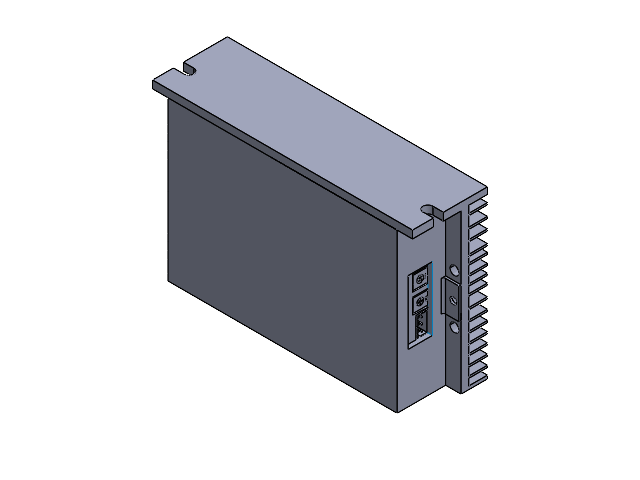
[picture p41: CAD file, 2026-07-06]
Solidworks/2- Chassis/6- driver.SLDASM
1.1_15.STEP
1.1.STEP

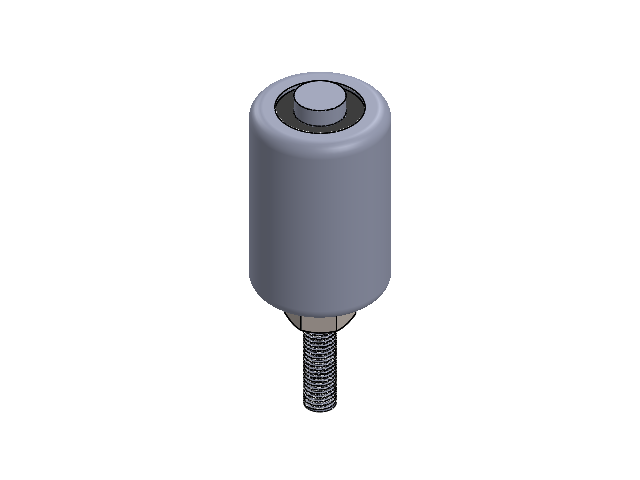
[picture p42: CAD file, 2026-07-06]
Solidworks/4- Assemblages/3- assemblage guidage.SLDASM
7- rouleau guidage
7- roulement guidage x 2
7- axe roulement guidage
plain washer 10673 type snl_iso
hex nut gradec_iso

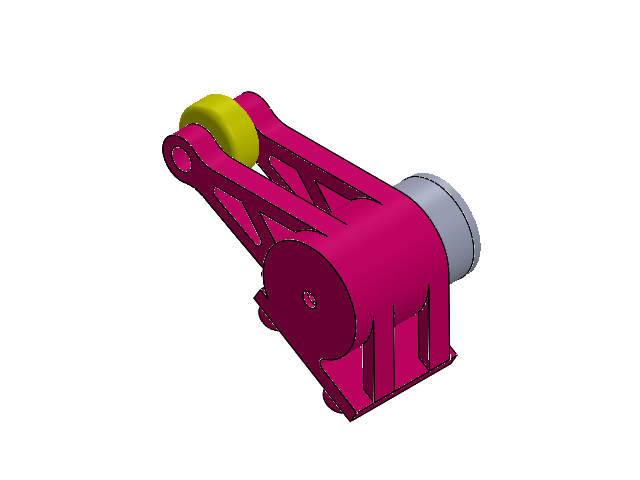
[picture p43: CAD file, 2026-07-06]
Solidworks/4- Assemblages/2- assemblage bras d_équilibre 2.SLDASM
6- support-ext roulement amazon 2
6- roue libre
7- roulement amazon
6- support roulement amazon

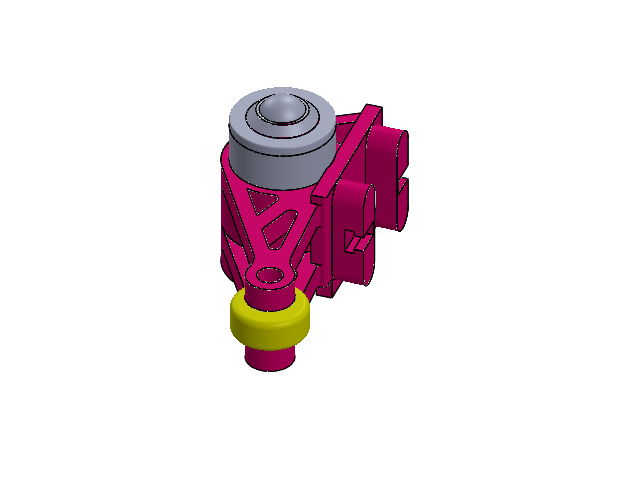
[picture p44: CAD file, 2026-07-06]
Solidworks/4- Assemblages/2- assemblage bras d_équilibre 1.SLDASM
6- roue libre
6- support-ext roulement amazon 1
7- roulement amazon
6- support roulement amazon

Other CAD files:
Solidworks/4- Assemblages/5- assemblage roue motrice + adaptateur.SLDASM
Solidworks/3- Roue inertielle/7 - maintien RI3.SLDPRT
Solidworks/3- Roue inertielle/7 - maintien Ri.SLDPRT
Solidworks/1- Roue/1- Lame 60deg.SLDPRT
Solidworks/2- Chassis/6 - adaptateur HPC - SUP008.SLDPRT
Solidworks/2- Chassis/6 - adaptateur2 HPC - SUP008.SLDPRT
Solidworks/2- Chassis/6- Roue motrice.SLDPRT
Solidworks/2- Chassis/6- adaptateur moteur.SLDPRT
Solidworks/2- Chassis/6- chassis découpé.SLDPRT
Solidworks/2- Chassis/6- chassis socles.SLDPRT
Solidworks/2- Chassis/6- hpc_SUP-008_SS_1.sldprt
Solidworks/2- Chassis/6- hpc_SUP-008_SS_2.sldprt
Solidworks/2- Chassis/6- hpc_SUP-008_SS_3.sldprt
Solidworks/2- Chassis/6- moteur roue motrice.SLDPRT
Solidworks/2- Chassis/6- plaque adaptateur chassis.SLDPRT
Solidworks/2- Chassis/6- roue libre.SLDPRT
Solidworks/2- Chassis/6- support roulement amazon.SLDPRT
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

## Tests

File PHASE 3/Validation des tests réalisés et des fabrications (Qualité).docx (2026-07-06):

Validation des tests réalisés et des fabrications

- Fabrication

Au niveau de la fabrication, on a rencontré quelques problèmes, notamment au niveau des impressions 3D.

La roue principale du robot est découpée en douze parties afin de pouvoir être imprimée. Cependant, comme la largeur de notre roue était de 30cm, on ne pouvait imprimer que sur une seule imprimante 3D. Ainsi, le temps d’impression et d’assemblage des douze parties de la roue ont pris énormément de temps. En conséquence, la partie électronique n’a disposé que d’un mois pour réaliser tous ses tests sur le robot.

Les modifications de certaines pièces avant impression ont participé au retard de l’assemblage final du robot puisqu’il était nécessaire d’en imprimer de nouvelles, cette fois-ci conformes à nos attentes pour pouvoir assembler le robot comme on l’avait pensé.

Passons maintenant aux pièces majeures de notre robot pour lesquelles nous avons rencontré des problèmes.

La plaque du bâti était de trop grande dimension pour entrer dans une imprimante 3D et donc nous avons dû découper une plaque de PVC brut pour réaliser la pièce. De même, nous avons dû réaliser à la main les trous de perçage pour pouvoir assembler la pièce au robot ainsi que fixer nos différents composants dessus.

Après l’impression de notre roue d’inertie, le cercle n’était pas parfait, ce qui a donc entraîné un jeu entre notre roue d’inertie et ses composants en contact lors de son installation dans le robot. Pour parer à ce programme, nous avons déplacé un de nos rouleaux de maintien contre notre roue d’inertie.

Les supports des roulements Amazon, positionnés dans les bras d’équilibre, avaient aussi du jeu au montage. Cependant, comme ce sont de petites pièces, nous avons pu ajuster le dimensionnement des supports à nos roulements et réimprimer les supports pour supprimer le jeu créé.

Sur l’un de nos deux moteurs, l’arbre était plein. Ainsi, nous avons dû créer une pièce qui puisse se positionner sur cet axe et disposait d’un méplat pour transmettre le mouvement du moteur à la roue. Or, cette pièce devait être solide et très peu déformable pour utiliser une Frette de serrage. Nous l’avons donc usiné en aluminium au tour.

- Tests réalisés

Dans un premier temps, nous avons commencé à réaliser nos tests avec uniquement les drivers reliés à une alimentation afin de s’assurer d’aucunes erreurs de montage. Ces tests nous ont principalement permis de comprendre le fonctionnement des drivers.

Nous avons ensuite réalisé les tests sur les moteurs, chacun séparément, pour s’assurer du bon fonctionnement des programmes Arduino codés. L’étape suivante a été de tester le bon fonctionnement des deux moteurs en simultanément afin de pouvoir réaliser l’avancement du robot mais aussi sa rotation lorsqu’il est en mouvement.

Après quelques modifications dans nos programmes pour réussir à piloter les deux moteurs en même temps, nous avons testé la mise en rotation des deux moteurs pilotés par le joystick du site.

Puis, lorsque le robot a été assemblé, nous avons pu commencer les tests des moteurs dans le robot. Après quelques essais et quelles frayeurs, le robot tournait et avançait mais on ne pouvait pas régler la vitesse.

En effet, lorsqu’on voulait faire avancer le robot, le simple fait d’avancer le joystick vers l’avant produisait une accélération soudaine et rapide que nous étions incapable de contrôler par manque d’asservisement. Pour la rotation du robot, le fait que l’accélération soit progressive ne nous permettait pas de beaucoup tourner.

Suite à ces tests, on a décidé de changer le design du site afin de séparer les deux mouvements : la rotation et l’avancement. Nous avons donc remplacé le joystick par une barre qui commande l’accélération de notre robot pour qu’il avance ou recule et deux boutons, un à gauche et un à droite, pour les rotations. Avec cette nouvelle interface, lorsqu’on glisse le doigt le long de la barre d'accélération, on peut gérer la vitesse de notre robot. Lorsqu'on veut le faire avancer, on va diriger le curseur vers le haut et pour le faire reculer, on va glisser le curseur vers le bas. Lorsqu’on appuie sur les boutons, on envoie directement l’accélération maximale du moteur dans la roue d’inertie afin de pouvoir entraîner la rotation du robot pour tourner à gauche ou à droite.

- Qualité du prototype

Nous avons rempli les contraintes du cahier des charges. Ainsi, le prototype est pleinement fonctionnel. Afin d’atteindre tous nos objectifs, nous avons préféré nous concentrer sur les performances que sur l’esthétisme du robot.

Avec un peu plus de temps, on aurait pu peaufiner certaines pièces pour avoir un prototype avec des finitions plus propres. De même pour le site, on aurait pu activer d’autres fonctionnalités secondaires.

Avec les tests sur le robot, on s’est aperçu que le PLA de notre roue principale commençait à légèrement fondre à certains endroits à cause des frottements avec le sol lorsqu’on le fait rouler.

- Améliorations futures

Pour les années futures, il faudrait revoir l’efficacité du PLA dans la durabilité du projet. De plus, lors de son fonctionnement, avec les roulements et les frottements, le robot est très bruyant. En revoyant l’esthétisme et l’adaptation du robot à un environnement plus contraint, il faudra sûrement construire le robot avec d’autres matériaux plus résistants, durables et moins bruyants.

L’asservissement sera aussi à revoir afin de pouvoir mieux piloter le robot et pouvoir exploiter toutes les intensités que peuvent fournir les moteurs. L’idée du pilotable par joystick sera peut-être à reprendre.

Afin que notre robot puisse évoluer dans un environnement réel, avec des obstacles et des conditions météos à respecter, on pourrait intégrer au robot une intelligence artificielle qui puisse identifier les obstacles à éviter.

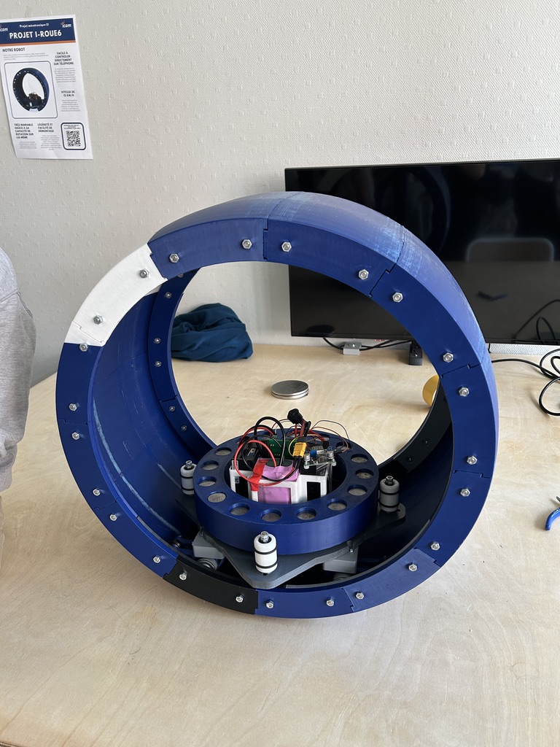
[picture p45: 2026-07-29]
Vidéo test/Tests finaux/A5F89C8A-1957-48EF-8640-1ACD8461A539_1_105_c.jpeg

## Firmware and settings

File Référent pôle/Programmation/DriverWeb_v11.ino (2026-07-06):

#include <WiFi.h>
#include <WiFiClient.h>
#include <WiFiAP.h>
#include <DNSServer.h>
#include <WebSocketsServer.h>
#include <ArduinoJson.h>
#include <Arduino.h>

// Définition des broches moteurs
#define PWM_CHANNEL_1 0
#define PWM_CHANNEL_2 1
#define PWM_FREQ 1000
#define PWM_RESOLUTION 8
#define SV1_PIN 26  // Signal vitesse moteur 1. D3
#define SV2_PIN 25  // Signal vitesse moteur 2. D2
#define FR1_PIN 4  // Sens moteur 1. D12
#define FR2_PIN 14  // Sens moteur 2. D6
#define EN1_PIN 16  // Activation moteur 1. D11
#define EN2_PIN 13  // Activation moteur 2. D7
#define PG1_PIN 12   // Retour vitesse moteur 1. D13
#define PG2_PIN 17   // Retour vitesse moteur 2. D10
#define NUM_POLE_PAIRS 2

// Nom et mot de passe du Wi-Fi
const char *ssid = "ESP32_BB8";
const char *password = "StarWars"; // Au moins 8 caractères obligatoires !

// Adresse IP du point d'accès
IPAddress apIP(192, 168, 4, 1);
IPAddress netMsk(255, 255, 255, 0);

// Serveur DNS
DNSServer dnsServer;

// Serveur HTTP et WebSocket
WiFiServer server(80);
WebSocketsServer webSocket(81);

// Variables moteurs et de contrôle
volatile unsigned long pulseCount1 = 0, pulseCount2 = 0;
unsigned long lastRPMTime = 0;
float rpm1 = 0, rpm2 = 0;
const unsigned long rpmInterval = 100;
int speedY = 0, speedX = 0;  // Ces variables seront mises à jour via WebSocket
int currentSpeedY = 0;      // Vitesse actuelle moteur 1
const int rampStep = 5;     // Incrément de rampe (vitesse de transition)
unsigned long previousMillis = 0;
const int rampInterval = 20; // temps entre chaque incrément (en ms)
int pwmMaxY = 20;  // Valeur initiale max pour l'avant/arrière en %

// Page HTML simplifiée pour tester la connexion
const char *Accueil = R"rawliteral(
<!DOCTYPE html>
<html>
    <head>
        <meta charset="UTF-8">
        <meta name="viewport" content="width=device-width, initial-scale=1.0">
        <title>Accueil BB-8</title>
    </head>

    <body style="font-family: Arial;
    text-align: center; 
    padding: 20px;
    width: 70%;
    height: 25%;

    position: absolute;
    top: 25%; 
    left: 8%;

    border: 2px solid #ccc;
    border-radius: 10px;
    box-shadow: 4px 4px 10px rgba(0, 0, 0, 0.2);
    background-color: white;
    font-size: 16px;">
        <h1>Bienvenue sur le controleur BB8</h1>
        <a href="/Joystick" style="display: inline-block; 
        padding: 10px 20px; 
        background-color: #ff9900; 
        color: #ffffff; 
        text-decoration: none; 
        border-radius: 5px; 
        font-size: large;">Accéder au Joystick</a>
    </body>
</html>
)rawliteral";

const char *Joystick = R"rawliteral(
<!DOCTYPE html>
<html lang="fr">
  <head>
    <meta charset="UTF-8">
    <meta name="viewport" content="width=device-width, initial-scale=1.0">
    <title>Contrôle BB-8</title>
    <style>
      body {
        font-family: Arial, sans-serif;
        text-align: center;
        background-color: white;
        color: #080808;
        margin: 0;
        padding: 20px;
      }
      h1 {
        margin-bottom: 30px;
      }
      .controls {
        display: flex;
        justify-content: center;
        align-items: center;
        gap: 40px;
      }
      .joystick {
        display: flex;
        flex-direction: column;
        align-items: center;
        gap: 15px;
      }
      input[type=range] {
        -webkit-appearance: none;
        appearance: none;
        width: 40px;       /* largeur totale du slider */
        height: 300px;
        background: transparent;
        margin: 0;
        padding: 0;
        position: relative;
      }

      /* Track - barre verticale plus épaisse */
      input[type=range]::-webkit-slider-runnable-track {
        width: 8px;            /* épaisseur de la barre */
        height: 100%;
        background: #ff9900;
        border-radius: 4px;
        margin: 0 auto;        /* centre horizontal */
      }

      /* Pouce (thumb) */
      input[type=range]::-webkit-slider-thumb {
        -webkit-appearance: none;
        appearance: none;
        width: 28px;            /* diamètre du curseur */
        height: 28px;
        background: white;
        border: 2px solid #333;
        border-radius: 50%;
        margin-left: -10px;     /* recentre horizontalement le pouce sur la barre */
        cursor: pointer;
        position: relative;
        z-index: 1;
        box-shadow: 0 0 4px rgba(0,0,0,0.3);
      }

      /* Firefox Track */
      input[type=range]::-moz-range-track {
        width: 8px;
        height: 300px;
        background: #ff9900;
        border-radius: 4px;
        margin: 0 auto;
      }

      /* Firefox Thumb */
      input[type=range]::-moz-range-thumb {
        width: 28px;
        height: 28px;
        background: white;
        border: 2px solid #333;
        border-radius: 50%;
        cursor: pointer;
        position: relative;
        z-index: 1;
        box-shadow: 0 0 4px rgba(0,0,0,0.3);
      }

      /* Important : orientation verticale */
      input[type=range] {
        writing-mode: bt-lr;  /* de bas en haut */
        -webkit-appearance: slider-vertical;
      }

      .buttons {
        display: flex;
        flex-direction: column;
        gap: 20px;
      }
      button {
        padding: 25px 40px;
        font-size: 28px;
        background-color: #ff9900; 
        color: white;
        border: none;
        border-radius: 10px;
        cursor: pointer;
        transition: background-color 0.2s;
        user-select: none;
        -webkit-user-select: none;
        -webkit-touch-callout: none;
        touch-action: manipulation;
      }
      button:active {
        background-color: #ff9900;
      }
      svg {
        width: 100px;
        height: 100px;
        margin-top: 30px;
      }
      html, body {
        overflow: hidden;
        height: 100%;
        margin: 0;
        padding: 0;
      }
    </style>
  </head>
<body>
  <h1>Contrôle BB-8</h1>
  <div class="controls">
    <div class="buttons">
      <button
        id="leftButton"
        draggable="false"
        ontouchstart="startMove(-100, 0)" 
        ontouchend="stopMove()"
        onmousedown="startMove(-100, 0)" 
        onmouseup="stopMove()"
      >Gauche</button>

      <button
        id="rightButton"
        draggable="false"
        ontouchstart="startMove(100, 0)" 
        ontouchend="stopMove()"
        onmousedown="startMove(100, 0)" 
        onmouseup="stopMove()"
      >Droite</button>

    </div>
    <div class="joystick">
      <input id="ySlider" type="range" min="-100" max="100" value="0" oninput="updateY(this.value)" />
      <label>Avant / Arrière</label>
    </div>
  </div>

  <script>
    let socket;
    let xValue = 0;
    let yValue = 0;
    let sendInterval;

    window.onload = () => {
      socket = new WebSocket("ws://" + location.hostname + ":81");
      socket.onopen = () => {
        console.log("WebSocket connecté !");
        sendInterval = setInterval(sendJoystickData, 100); // ENVOI RÉGULIER
      };
      socket.onerror = e => console.error("Erreur WebSocket:", e);

      // Empêche scroll lors du toucher des boutons
      const leftButton = document.getElementById("leftButton");
      const rightButton = document.getElementById("rightButton");
      [leftButton, rightButton].forEach(button => {
        button.addEventListener("touchstart", e => e.preventDefault(), { passive: false });
      });
      // Reset du joystick à 0 quand on relâche
      const ySlider = document.getElementById("ySlider");
      const resetJoystick = () => {
        ySlider.value = 0;
        updateY(0);
      };
      ySlider.addEventListener("mouseup", resetJoystick);
      ySlider.addEventListener("touchend", resetJoystick);
    };

    function updateY(val) {
      yValue = parseInt(val);

      // Récupère l'élément slider
      const ySlider = document.getElementById("ySlider");

      // Calcule la progression entre 0 et 1
      const progress = (val - ySlider.min) / (ySlider.max - ySlider.min);

      // Met à jour le dégradé vertical de la barre
      ySlider.style.background = `linear-gradient(to top, blue ${progress * 100}%, #ddd ${progress * 100}%)`;

      sendJoystickData();
    }

    function startMove(x, y) {
      xValue = x;
      yValue = yValue; // garde la valeur actuelle
      sendJoystickData();
      if (sendInterval) clearInterval(sendInterval);{
        sendInterval = setInterval(sendJoystickData, 100);
      }
    }

    function stopMove() {
      xValue = 0;
      sendJoystickData();
      clearInterval(sendInterval);
    }

    function getSpeedColor(x, y) {
      const speed = Math.sqrt(x * x + y * y); // 0 à ~141
      const normalized = Math.min(speed / 141, 1);
      const r = Math.round(46 + normalized * (231 - 46));   // 46 → 231
      const g = Math.round(204 - normalized * (204 - 76));  // 204 → 76
      const b = Math.round(113 - normalized * (113 - 60));  // 113 → 60
      return `rgb(${r}, ${g}, ${b})`;
    }

    function sendJoystickData() {
      if (!socket || socket.readyState !== WebSocket.OPEN) return;
      const data = { x: xValue, y: yValue };
      socket.send(JSON.stringify(data));
    }
  </script>
</body>
</html>
)rawliteral";


// Prototypes des fonctions utilisées
void webSocketEvent(uint8_t num, WStype_t type, uint8_t *payload, size_t length);
void updateRPM();
void updateMotors();
void updateRampSpeedY();

// Gestion des interruptions pour le comptage des pulses
void IRAM_ATTR onPulse1() { pulseCount1++; }
void IRAM_ATTR onPulse2() { pulseCount2++; }

void setup() {
    Serial.begin(115200);
    Serial.println("\n Démarrage de l'ESP32...");

    // Forcer l'ESP32 en mode Point d'accès (AP)
    WiFi.mode(WIFI_AP);
    WiFi.softAPConfig(apIP, apIP, netMsk);

    // Démarrer le point d'accès Wi-Fi
    if (WiFi.softAP(ssid, password)) {
        Serial.println("Point d'accès activé !");
        Serial.print("SSID : ");
        Serial.println(ssid);
        Serial.print("Adresse IP : ");
        Serial.println(WiFi.softAPIP());
    } else {
        Serial.println("Échec de la création du point d'accès !");
        return;
    }

    // Démarrer le serveur DNS
    dnsServer.start(53, "*", apIP);

    // Démarrer le serveur Web et WebSocket
    server.begin();
    webSocket.begin();
    webSocket.onEvent(webSocketEvent);

    Serial.println("Serveur Web et WebSocket démarrés.");

    // Configuration des moteurs
    ledcSetup(PWM_CHANNEL_1, PWM_FREQ, PWM_RESOLUTION);
    ledcSetup(PWM_CHANNEL_2, PWM_FREQ, PWM_RESOLUTION);
    ledcAttachPin(SV1_PIN, PWM_CHANNEL_1);
    ledcAttachPin(SV2_PIN, PWM_CHANNEL_2);
    pinMode(FR1_PIN, OUTPUT);
    pinMode(FR2_PIN, OUTPUT);
    pinMode(EN1_PIN, OUTPUT);
    pinMode(EN2_PIN, OUTPUT);
    pinMode(PG1_PIN, INPUT);
    pinMode(PG2_PIN, INPUT);
    attachInterrupt(digitalPinToInterrupt(PG1_PIN), onPulse1, RISING);
    attachInterrupt(digitalPinToInterrupt(PG2_PIN), onPulse2, RISING);
}

void loop() {
    dnsServer.processNextRequest();
    webSocket.loop();
    updateRPM();
    updateRampSpeedY();  // Rampe non bloquante
    updateMotors();

    WiFiClient client = server.available();
    if (client) {
        String request = "";
        while (client.connected()) {
            if (client.available()) {
                char c = client.read();
                request += c;
                if (c == '\n' && request.endsWith("\r\n\r\n")) {
                break;
                }
                if (c == '\n') {
                    if (request.indexOf("GET /generate_204") >= 0 || 
                        request.indexOf("GET /hotspot-detect.html") >= 0 ||
                        request.indexOf("GET /ncsi.txt") >= 0) {

                        client.println("HTTP/1.1 302 Found");
                        client.println("Location: http://192.168.4.1/");
                        client.println("Connection: close");
                        client.println();
                        client.stop();
                        return;
                    }

                    if (request.indexOf("GET /Joystick") >= 0) {
                        client.println("HTTP/1.1 200 OK");
                        client.println("Content-type:text/html");
                        client.println();
                        client.print(Joystick);
                    } else {
                        client.println("HTTP/1.1 200 OK");
                        client.println("Content-type:text/html");
                        client.println();
                        client.print(Accueil);
                    }
                    client.println();
                    break;
                }
            }
        }
        client.stop();
    }
}

void updateRPM() {  //Calcule la vitesse réelle des moteurs (en RPM) à partir des pulses.
    unsigned long currentTime = millis();  // Récupère le temps actuel en millisecondes
    if (currentTime - lastRPMTime >= rpmInterval) {  // Vérifie si l'intervalle de temps est écoulé depuis la dernière mise à jour
        float dt = (currentTime - lastRPMTime) / 1000.0;  // Calcule le temps écoulé (en secondes) depuis la dernière mesure

        // Désactive les interruptions pour éviter des modifications concurrentes du compteur de pulses
        noInterrupts();
        unsigned long pulses1 = pulseCount1;  // Copie le nombre de pulses du moteur 1
        pulseCount1 = 0;                      // Réinitialise le compteur
        interrupts();                         // Réactive les interruptions

        noInterrupts();
        unsigned long pulses2 = pulseCount2;  // Idem pour le moteur 2
        pulseCount2 = 0;
        interrupts();

        // Calcule la vitesse de rotation (RPM) pour chaque moteur
        // Formule : (nombre de pulses / durée en secondes) * 60 secondes / (3 * nombre de paires de pôles)
        rpm1 = (pulses1 / dt * 60.0) / (3.0 * NUM_POLE_PAIRS);
        rpm2 = (pulses2 / dt * 60.0) / (3.0 * NUM_POLE_PAIRS);

        // Affiche les valeurs de RPM dans la console série pour le débogage
        //Serial.printf("M1: %.2f RPM | M2: %.2f RPM\n", rpm1, rpm2);

        lastRPMTime = currentTime;  // Met à jour le temps de dernière mesure
    }
}


void updateMotors() {  //Applique les consignes de vitesse et de direction aux moteurs.
    // Contrôle du moteur 1 (avance/recul) avec vitesse progressive via currentSpeedY
    // Détermine le sens de rotation (avant ou arrière)
    digitalWrite(FR1_PIN, currentSpeedY >= 0 ? HIGH : LOW);
    // Active ou désactive le moteur (LOW pour activer selon le câblage)
    digitalWrite(EN1_PIN, currentSpeedY != 0 ? LOW : HIGH);
    // Envoie un signal PWM pour ajuster la vitesse
    ledcWrite(PWM_CHANNEL_1, constrain(abs(currentSpeedY), 0, 255));

    // Contrôle du moteur 2 (gauche/droite), sans rampe, directement selon speedX
    digitalWrite(FR2_PIN, speedX >= 0 ? HIGH : LOW);
    digitalWrite(EN2_PIN, speedX != 0 ? LOW : HIGH);
    ledcWrite(PWM_CHANNEL_2, constrain(abs(speedX), 0, 255));
}


void updateRampSpeedY() {  //Permet une montée ou descente progressive de la vitesse sur l'axe Y pour éviter les à-coups.
    unsigned long currentMillis = millis();  // Récupère le temps actuel
    if (currentMillis - previousMillis >= rampInterval) {  // Vérifie si le temps de lissage est écoulé
        previousMillis = currentMillis;  // Met à jour le temps de la dernière rampe

        // Augmente progressivement la vitesse actuelle vers la consigne (accélération douce)
        if (currentSpeedY < speedY) {
            currentSpeedY += rampStep;
            if (currentSpeedY > speedY) currentSpeedY = speedY;  // Ne pas dépasser la cible
        }
        // Diminue progressivement la vitesse actuelle vers la consigne (décélération douce)
        else if (currentSpeedY > speedY) {
            currentSpeedY -= rampStep;
            if (currentSpeedY < speedY) currentSpeedY = speedY;  // Ne pas descendre en dessous de la cible
        }
    }
}


// Fonction appelée automatiquement lorsqu'un événement WebSocket survient
void webSocketEvent(uint8_t num, WStype_t type, uint8_t *payload, size_t length) {
    if (type == WStype_TEXT) {  // Si le message reçu est un texte (JSON dans notre cas)
        
        // Création d’un document JSON statique pour parser le message
        StaticJsonDocument<128> doc;

        // Tentative de désérialisation du message JSON reçu
        DeserializationError error = deserializeJson(doc, payload, length);

        if (!error) {  // Si le parsing JSON a réussi

            // Lecture des valeurs "x" et "y" dans le message JSON
            int x = doc["x"];  // Valeur de commande horizontale (gauche/droite)
            int y = doc["y"];  // Valeur de commande verticale (avant/arrière)

            // Conversion (mapping) des valeurs -100 à 100 vers des valeurs PWM utilisables
            // Moteur 2 : rotation gauche/droite
            speedX = map(x, -100, 100, -255, 255);  

            // Moteur 1 : déplacement avant/arrière (plage réduite volontairement)
            speedY = map(y, -100, 100, -255*pwmMaxY/100, 255*pwmMaxY/100);  // Limitation de la vitesse max pour éviter d’aller trop vite

            // Affichage des valeurs reçues et des commandes PWM pour débogage
            Serial.printf("Reçu -> x: %d, y: %d\n", x, y);
            Serial.printf("PWM -> M1: %d | M2: %d\n", abs(speedY), abs(speedX));
        } else {
            // Message d'erreur si le parsing JSON échoue
            Serial.println("Erreur de parsing JSON");
         }
    }   
    else {
        // Gestion d'autres types de messages WebSocket (ex: binaires, ping/pong, etc.)
        Serial.printf("WebSocket non géré: %d\n", type);
    }
}

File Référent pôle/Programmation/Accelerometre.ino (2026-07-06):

#include <Wire.h>
#include <SparkFun_BNO08x_Arduino_Library.h>

BNO08x myIMU;

void setup() {
    Serial.begin(115200);
    Wire.begin();

    if (!myIMU.begin()) {
        Serial.println("Erreur : BNO08x non détecté !");
        while (1);
    }

    Serial.println("BNO08x détecté !");
    
    // Activation du capteur d'accélération linéaire
    myIMU.enableLinearAccelerometer(50);  // Fréquence d'échantillonnage de 50Hz
}

void loop() {
    if (myIMU.wasReset()) {
        Serial.println("Le BNO08x a été réinitialisé !");
        myIMU.enableLinearAccelerometer(50);
    }

    if (myIMU.getSensorEvent()) {  // Vérifie si de nouvelles données sont disponibles
        float x = myIMU.getLinAccelX();
        float y = myIMU.getLinAccelY();
        float z = myIMU.getLinAccelZ();

        Serial.print("Accélération (m/s²) : X=");
        Serial.print(x, 2);
        Serial.print(" Y=");
        Serial.print(y, 2);
        Serial.print(" Z=");
        Serial.println(z, 2);
    }

    delay(100);
}

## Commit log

2026-07-29 Ajout d'image et de vidéo pour le README
2026-07-29 Changement taille de l'image
2026-07-29 Ajout de la vidéo de démo sous forme de gif
